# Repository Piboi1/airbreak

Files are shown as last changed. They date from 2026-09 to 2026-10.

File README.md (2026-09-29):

# MIT Rocket Team air brake – STL / STEP generator

`airbrake_stl.py` rebuilds the MIT Rocket Team (Prometheus) sliding-plate air brake.
It's pure Python 3 and needs no packages.

```
python3 airbrake_stl.py                 # extended (default)
python3 airbrake_stl.py --deploy 0      # retracted (any value 0..1)
python3 airbrake_stl.py --tube          # add the slotted 6 in airframe tube
python3 airbrake_stl.py --units in      # inches instead of mm
```

| Output | What it is |
|---|---|
| `airbrake_assembly.stl` | Whole assembly as one mesh (extended) |
| `airbrake_retracted.stl` | Same, with the leaves retracted |
| `airbrake_assembly.step` | **Open this one in CAD.** Exact geometry (true arcs, circles and cylinders, not facets); every part is one connected solid; 44 part instances, ready for Onshape mates and motion |
| `print/<part>_xN.stl` | One print-ready file per unique part, lying flat on the bed. `xN` is how many to print |
| `preview/motion.gif` | Rendered deployment cycle |

All files are in **millimetres**.

## Printing

| File | Qty | Notes |
|---|---|---|
| `frame_bottom_x1` | 1 | spoked frame that mounts in the tube |
| `tray_frame_x4` | 4 | ring segment either side of each tray |
| `tray_x2` | 2 | leaf guide tray (SLA resin in the real build) |
| `frame_middle_x1` | 1 | thin ring between the two trays |
| `leaf_x4` | 4 | 6061-T6 1/8 in plate in the real build |
| `hex_connector_x2` | 2 | double crank with a 1/4 in hex bore |
| `leaf_connector_x4` | 4 | links |
| `spacer_x4` | 4 | guide spacers under the servo bulkhead |
| `servo_bulkhead_x1` | 1 | |
| `servo_bracket_x2` | 2 | servo standoffs |
| `shaft_coupler_x1` | 1 | hex shaft to servo horn |
| `hex_shaft_x1` | 1 | or cut from 1/4 in steel hex stock |

Hardware you'll need to buy:
* 8 × #10 shoulder bolts (4 leaf pins, 4 crank pins)
* 8 × #10 washers
* 1 × large servo, about 1500 oz-in

Printed holes have 0.005 in (0.13 mm) radial clearance; change `HOLE_CLEAR` if your printer needs more.

## Onshape FeatureScript (`airbrake.fs`)

`airbrake.fs` builds the same air brake natively in Onshape, as real Onshape parts in meters.

1. In an Onshape document, create a **Feature Studio**. Replace its contents with `airbrake.fs` and commit.
2. Open a **Part Studio**. Add **MyCustomPart** from the custom features menu on the toolbar.
3. Adjust the options:
   * **Deployment (0–1):** 0 is stowed, 1 is fully out. Changing it rebuilds the model with the cranks, links and leaves moved to that position.
   * **Include servo / pins and washers / airframe tube:** toggles for those parts.
   * **Add mate connectors:** puts mate connectors on the shaft axis, every pin hole, and each leaf's slide direction.
4. For mates, insert the Part Studio into an Assembly and snap the mate connectors together:
   * **Revolute:** shaft to bottom frame; each leaf connector to its hex connector pin and its leaf pin.
   * **Fastened:** hex connectors to the shaft.
   * **Slider:** each leaf's slide connector to its tray's.

If Onshape reports a version error, replace the first two lines with the header from a newly created Feature Studio.

## Making it move in Onshape (STEP import)

Import `airbrake_assembly.step`. Onshape creates an Assembly tab with every part in its extended position. Then add these mates:

1. Group the frames, trays, tray frames, spacers, bulkhead, brackets and servo together, and fix the group.
2. Add a **Revolute** mate between the hex shaft and the bottom frame's bore. Fasten both hex connectors and the shaft coupler to the shaft.
3. Add a **Slider** mate from each leaf to its tray, along the channel.
4. Add a **Revolute** mate from each leaf connector to its crank pin hole on the hex connector.
5. Add a **Revolute** mate from each leaf connector to its pin hole on the leaf.

Dragging the hex shaft then drives all four leaves. The crank sweeps 90°, and each leaf travels exactly 2.25 in. At full extension the crank and link line up (dead centre), so drag on the leaves can't back-drive the servo.

## Accuracy

Values published on the MIT wiki:
* 4 sliding 6061-T6 leaves, each 3.5 in wide with 2.25 in extended (7.875 in² each, 31.5 in² total)
* two SLA trays stacked 90° apart, each spanning the full diameter and holding one opposing pair of leaves
* a hex connector and leaf connectors, driven by a servo on a bulkhead, with washers at the joints
* frames, spacers and a servo bulkhead
* 6 in series airframe (5.823 in ID / 6.00 in OD)

The team never published the other dimensions: plate thicknesses, frame sizes, stack
heights, linkage lengths and the servo's size. Those are estimates taken from the CAD
screenshots. The stack follows the PDR image, with 0.63 in between the two leaf levels.
All estimates are in the `PARAMETERS` block at the top of the script. The linkage is
re-solved automatically when you change them, and the script warns if a link would
hit the shaft.

Not modelled: radial screw holes into the airframe, fasteners, and the servo horn.

STL files are always triangle meshes, so they show triangle lines in any CAD tool. Use
them for printing, and use the STEP file for viewing and editing in CAD.

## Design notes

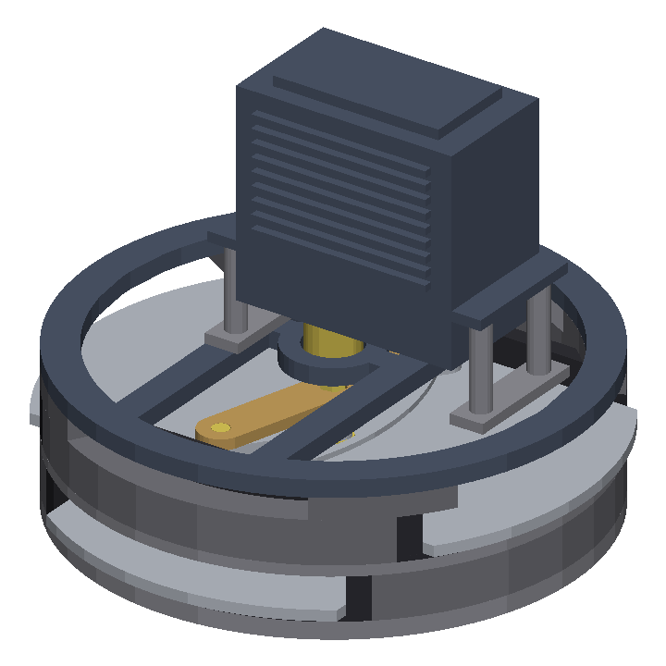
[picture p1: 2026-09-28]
preview/retracted.png

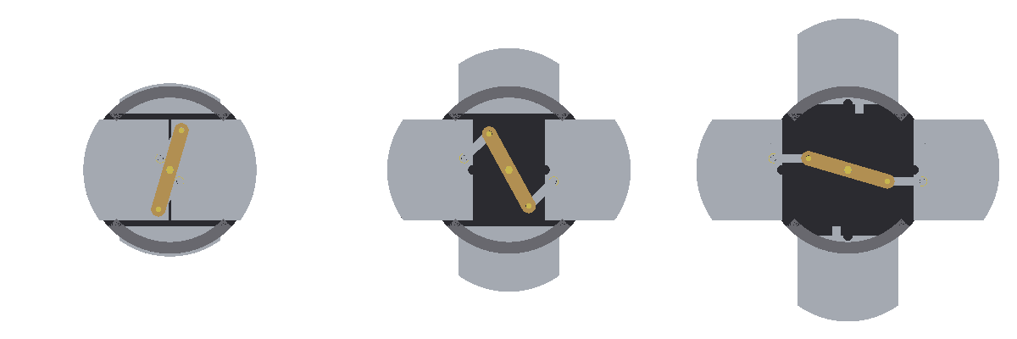
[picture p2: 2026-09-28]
preview/linkage_top.png

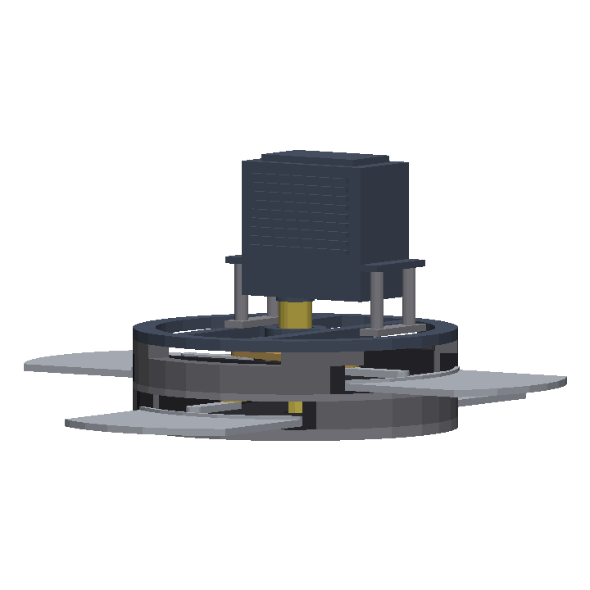
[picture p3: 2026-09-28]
preview/side.png

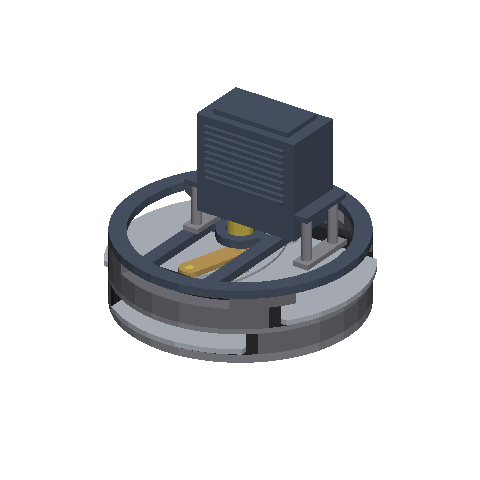
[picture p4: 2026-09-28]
preview/motion.gif

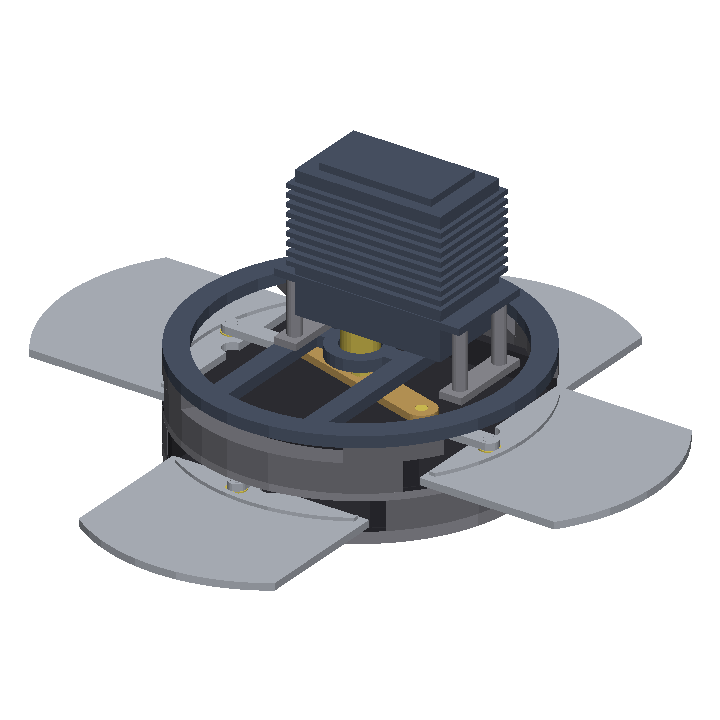
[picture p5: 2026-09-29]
preview/extended.png

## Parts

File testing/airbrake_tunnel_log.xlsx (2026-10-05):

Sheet: Settings
Air brake wind tunnel test log
Log every tunnel run on the Tunnel runs tab. Combined and Summary update by themselves.
How to use this workbook
1. Add each air brake version on the Designs tab (one row per version).
2. Log every tunnel measurement on Tunnel runs: one row per section (Nose, Air brake or Fin can) per run.
3. On Combined, add a row for each design, speed setpoint and deployment you tested. It averages repeat runs and adds the three sections together.
4. Summary shows drag coefficient against deployment and an estimated apogee for each design.
Blue text: values you type. Yellow fill: needs your number. Black text: formulas, leave them alone.
Need more rows? Select the last filled row on Tunnel runs or Combined and drag it down; the formulas copy with it.
Constants and inputs
Setting | Value | Unit | Source / note
Gas constant for dry air | 287.05 | J/(kg·K) | Standard value for dry air
Sutherland viscosity constant C1 | 1.458e-06 | kg/(m·s·K^0.5) | Sutherland's law for air (standard constants)
Sutherland temperature S | 110.4 | K | Sutherland's law for air (standard constants)
Gravity | 9.81 | m/s² | Standard gravity
Feet per metre | 3.28084 | ft/m | Unit conversion
Air density at launch site | 1.225 | kg/m³ | ISA sea level. Replace with your launch site value.
Target apogee | 800 | ft | Source: user-provided (ARC target)
Tunnel test-section area |  | m² | Fill in: width × height of your tunnel's test section
Blockage limit | 10% | fraction | Rule of thumb: above about 10% the walls inflate the drag reading

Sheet: Designs
Air brake designs
One row per version. Design ID is what the other tabs look up, so keep it short and unique.
Design ID | Description | Body tube OD (mm) | Reference area (m²) | Number of leaves | Leaf width (mm) | Leaf extension (mm) | Brake area, fully open (cm²) | Servo | Rocket mass (g) | CAD file / link | Notes
MIT-6in | Example: MIT Rocket Team CDR design (replace with your own) | 152.4 |  | 4 | 88.9 | 57.15 |  | 1500 oz-in industrial servo |  | airbrake.fs | Leaf size from the MIT wiki

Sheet: Tunnel runs
Wind tunnel runs
One row per section per run. Grey columns are calculated.
Run ID | Date | Design ID | Section | Deployment (%) | Speed setpoint (m/s) | Measured airspeed (m/s) | Measured force (N) | Tare force (N) | Air temp (°C) | Air pressure (kPa) | Model frontal area (cm²) | Notes | Air density (kg/m³) | Dynamic pressure (Pa) | Net drag (N) | Body OD (m) | Reference area (m²) | Section drag coefficient | Air viscosity (Pa·s) | Reynolds number | Blockage | Blockage check | Condition key
EX-1 | 2026-10-04 | MIT-6in | Air brake | 100 | 20 | 20.1 | 6.4 | 0.3 | 21 | 101.3 | 182.4 | Example row showing the format. Delete it.

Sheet: Combined
Whole-rocket drag from the three sections
Add one row per design, speed setpoint and deployment. Repeat runs are averaged; the three sections are added together.
 |  |  | Average net drag by section (N)
Design ID | Speed setpoint (m/s) | Deployment (%) | Nose | Air brake | Fin can | All three sections tested? | Total drag (N) | Average dynamic pressure (Pa) | Reference area (m²) | Whole-rocket drag coefficient | Air brake section drag, stowed (N) | Drag added by brakes (N) | Drag coefficient added by brakes
MIT-6in | 20 | 100

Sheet: Summary
Summary by design
Drag coefficients are averaged over every speed with all three sections tested.
Whole-rocket drag coefficient by brake deployment
Design ID | 0% open | 25% open | 50% open | 75% open | 100% open | Brake drag coefficient added at 100% | Tunnel runs logged
Estimated apogee
Vertical coast with constant drag, from burnout to apogee. Take burnout altitude and velocity from OpenRocket. Tunnel speeds are lower than flight speeds, so treat this as a comparison between designs.
Design ID | Coast mass (kg) | Burnout altitude (m) | Burnout velocity (m/s) | Drag coefficient, stowed | Drag coefficient, fully open | Reference area (m²) | Apogee, brakes stowed (ft) | Apogee, brakes open all coast (ft) | Target apogee (ft) | Can the brakes reach the target?

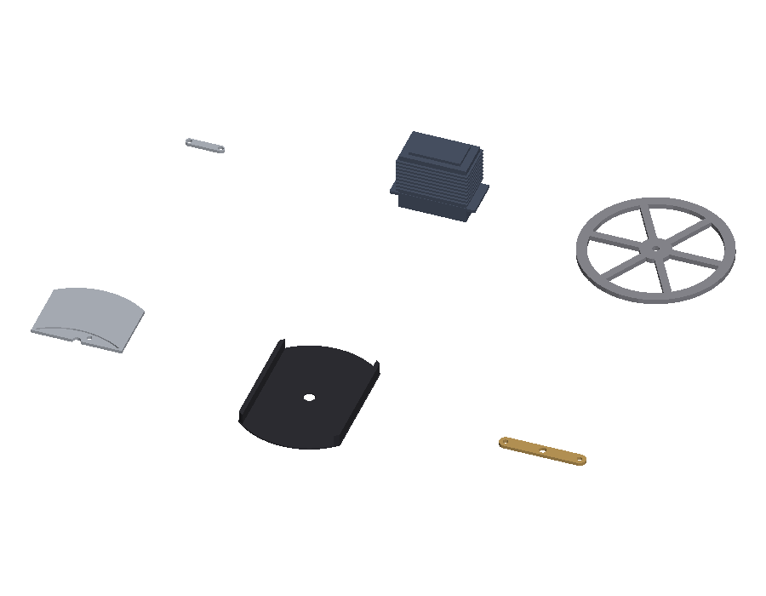
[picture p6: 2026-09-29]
preview/parts.png

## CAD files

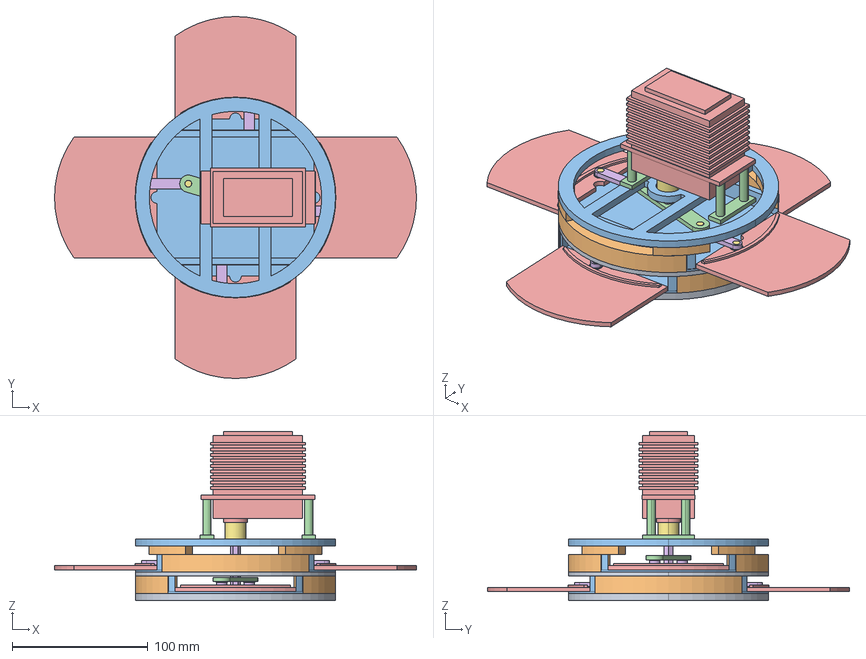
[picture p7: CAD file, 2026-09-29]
airbrake_assembly.step
266.7 x 266.7 x 124.6 mm
frame_bottom
tray_frame x 4
tray x 2
hex_connector x 2
leaf x 4
leaf_connector x 4
pin_leaf x 4
pin_crank x 4
washer x 8
frame_middle
spacer x 4
servo_bulkhead
servo_bracket x 2
servo
hex_shaft
shaft_coupler

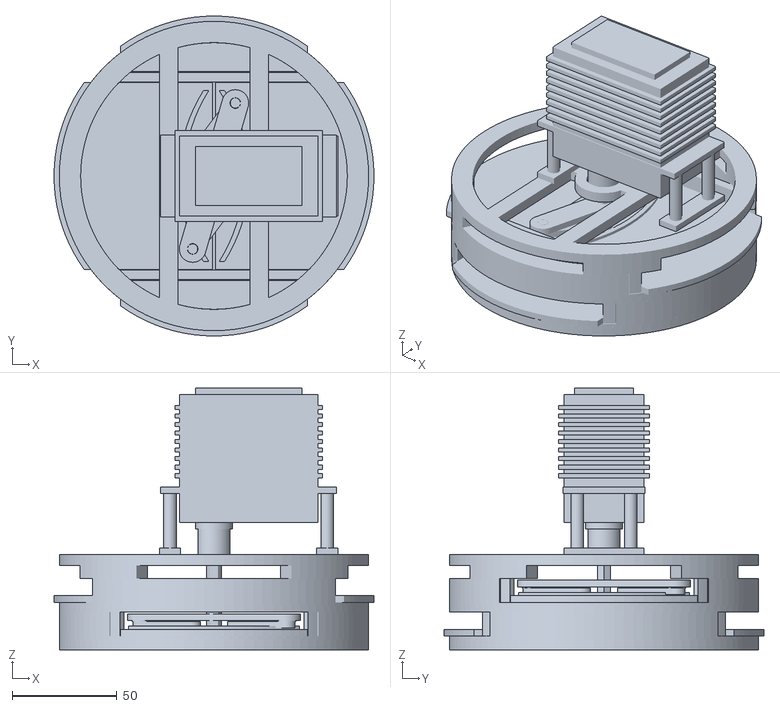
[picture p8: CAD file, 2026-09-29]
airbrake_retracted.stl
152.4 x 152.4 x 124.6

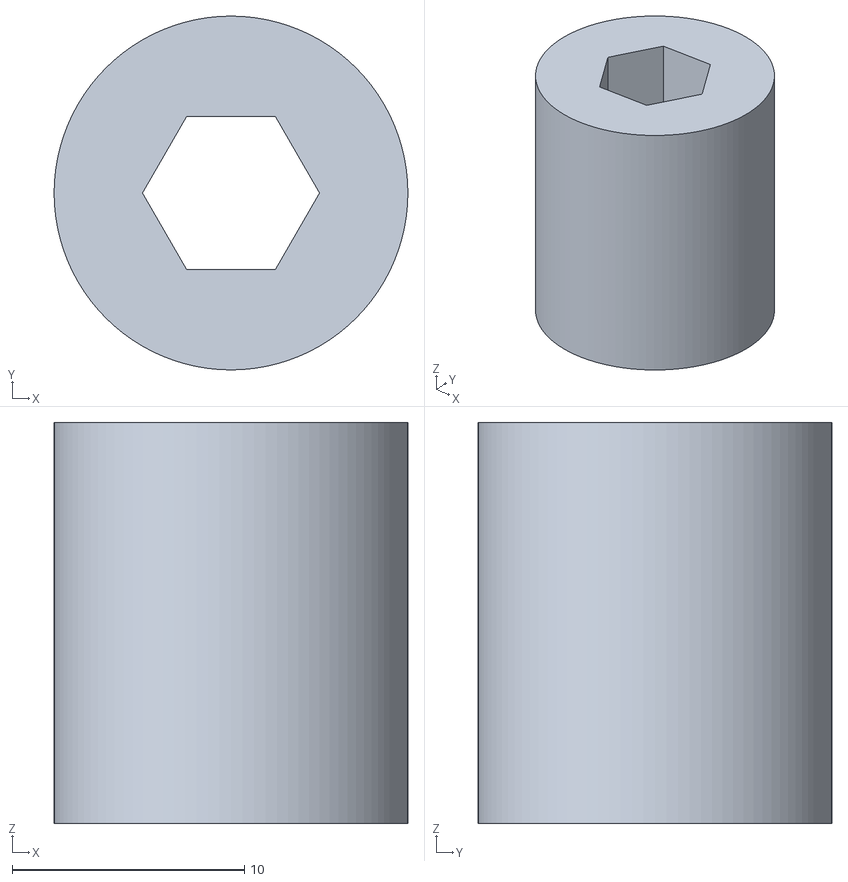
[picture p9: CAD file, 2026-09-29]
print/shaft_coupler_x1.stl
15.2 x 15.2 x 17.3

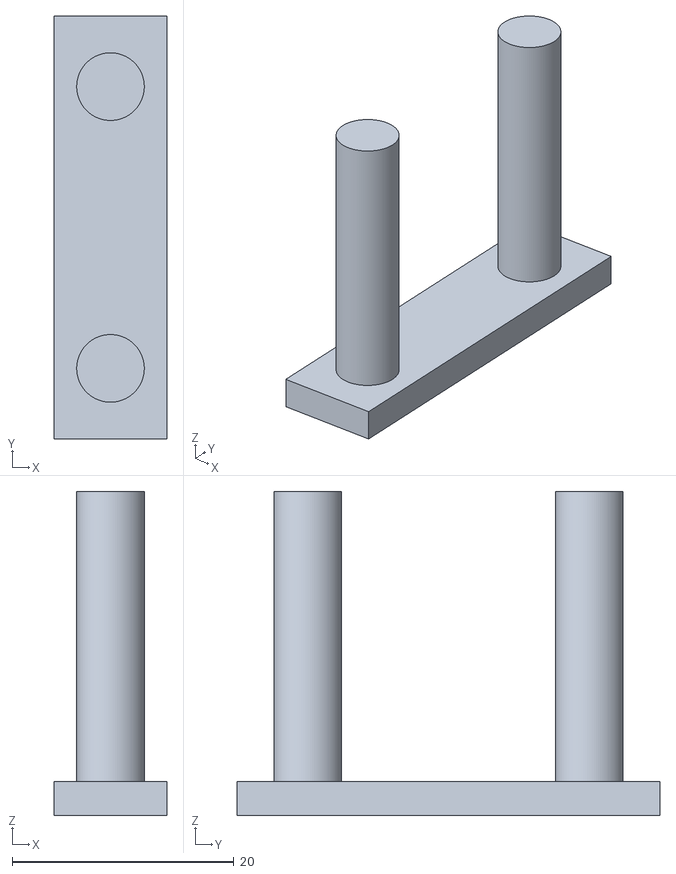
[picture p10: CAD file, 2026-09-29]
print/servo_bracket_x2.stl
10.2 x 38.1 x 29.2

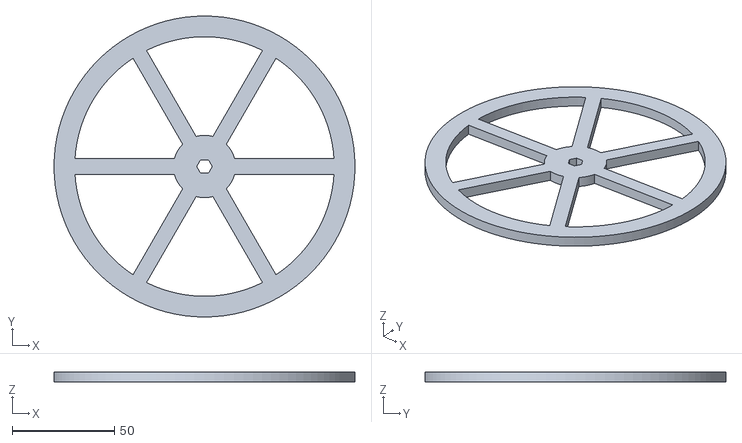
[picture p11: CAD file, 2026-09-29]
print/frame_bottom_x1.stl
147.3 x 147.3 x 5.08

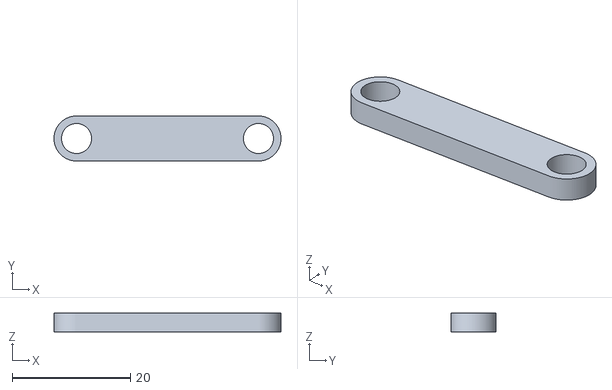
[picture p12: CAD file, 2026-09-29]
print/leaf_connector_x4.stl
38.4 x 7.62 x 3.17

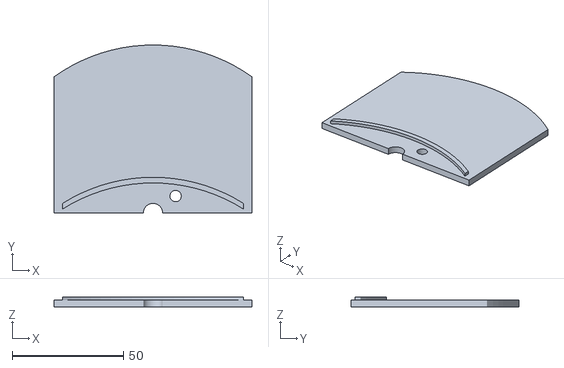
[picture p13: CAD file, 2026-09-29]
print/leaf_x4.stl
88.9 x 75.4 x 4.70

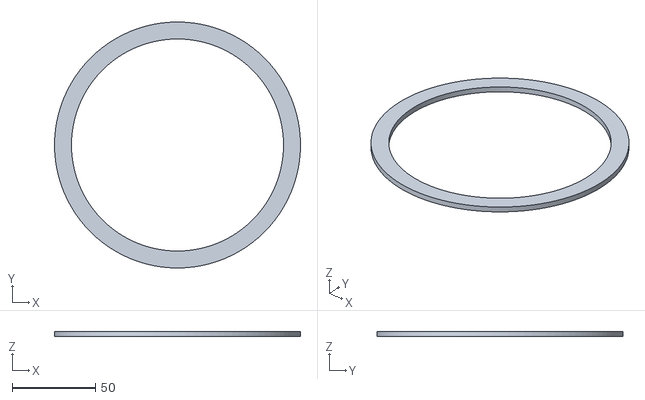
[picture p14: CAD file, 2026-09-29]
print/frame_middle_x1.stl
147.3 x 147.3 x 3.17

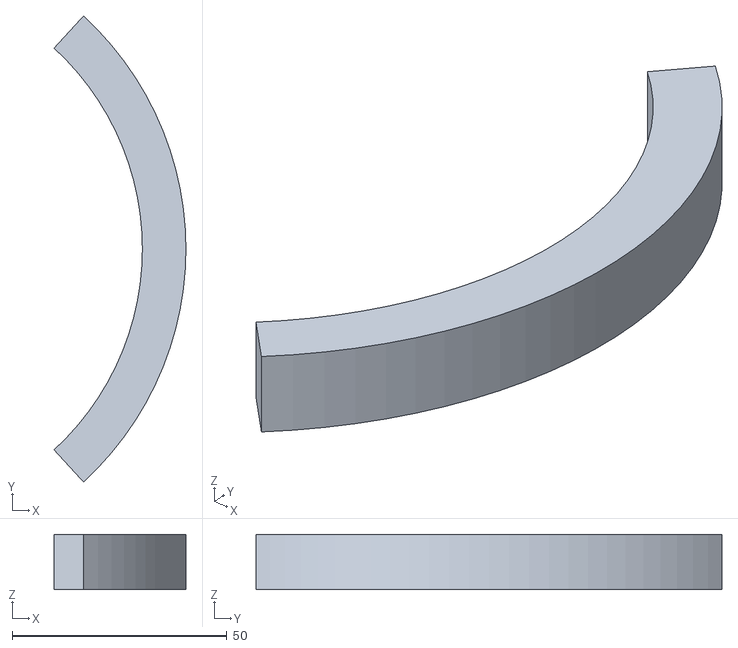
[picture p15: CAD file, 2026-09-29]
print/tray_frame_x4.stl
30.7 x 108.6 x 12.8

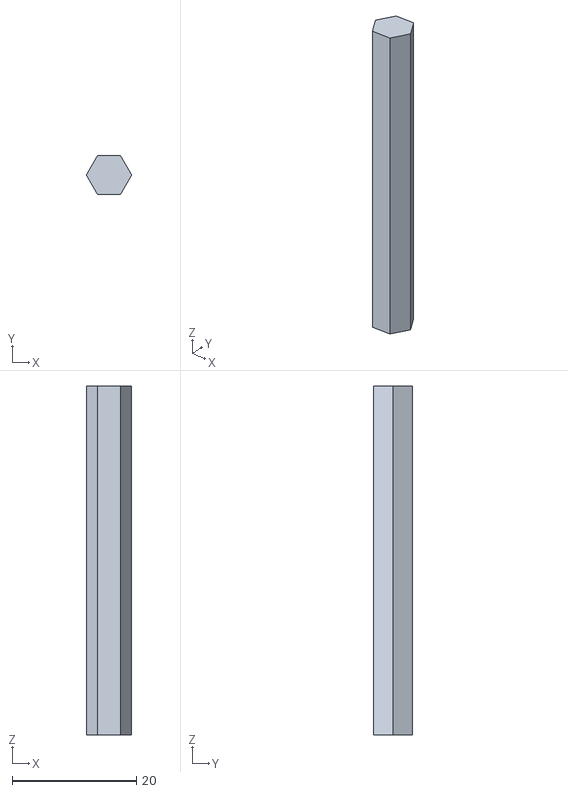
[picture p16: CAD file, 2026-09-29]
print/hex_shaft_x1.stl
7.33 x 6.35 x 56.3

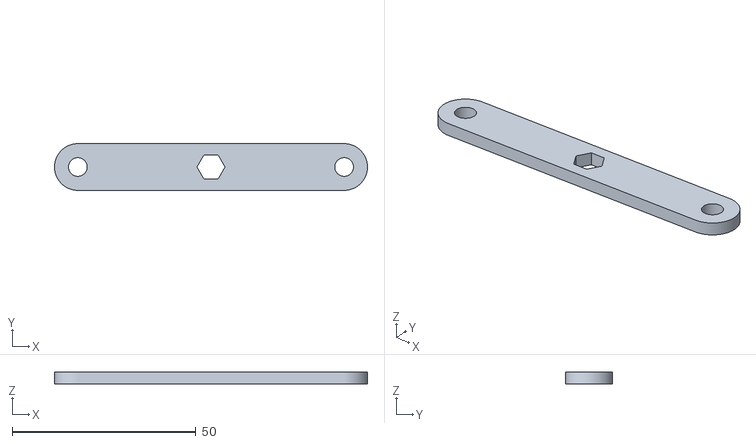
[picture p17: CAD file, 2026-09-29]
print/hex_connector_x2.stl
85.1 x 12.7 x 3.17

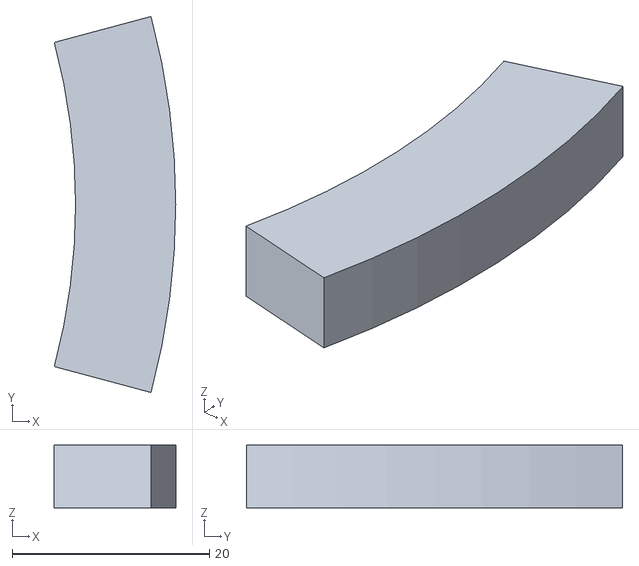
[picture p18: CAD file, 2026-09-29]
print/spacer_x4.stl
12.3 x 38.1 x 6.35

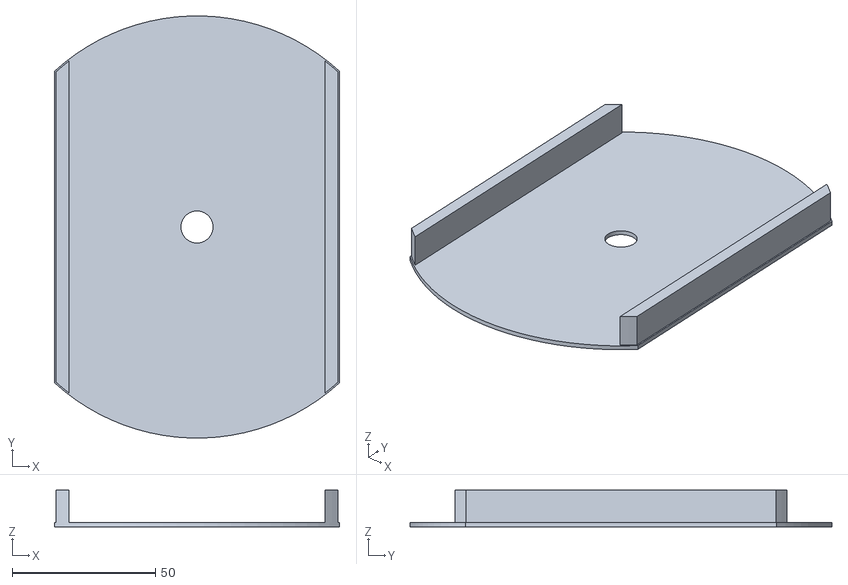
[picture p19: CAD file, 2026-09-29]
print/tray_x2.stl
99.6 x 147.2 x 12.8

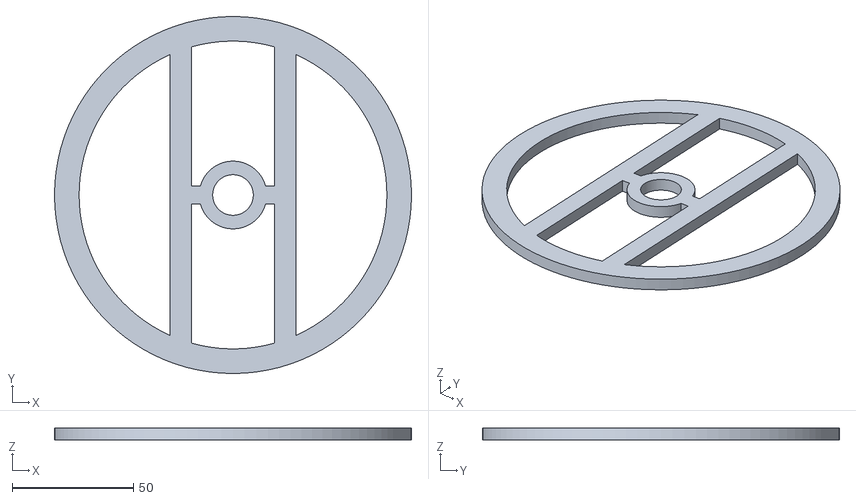
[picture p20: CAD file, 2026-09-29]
print/servo_bulkhead_x1.stl
147.3 x 147.3 x 5.08

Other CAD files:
airbrake_assembly.stl

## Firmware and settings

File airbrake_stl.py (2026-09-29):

#!/usr/bin/env python3
"""
MIT Rocket Team (Prometheus) air brake -- CDR configuration -- STL + STEP generator.

Reconstructed from the MIT Rocket Team wiki page "Air Brakes"
(wikis.mit.edu/confluence/display/RocketTeam/Air+Brakes) and its CAD screenshots.

What is taken directly from the wiki:
  * Sliding-plate design, 4 aluminium 6061-T6 leaves, one system on the sustainer
  * Leaf: 3.5 in wide x 2.25 in extended length  -> 7.875 (~7.88) in^2 per leaf,
    31.5 in^2 total
  * Leaves slide in SLA-printed trays, one tray per opposing pair of leaves, each
    tray spanning the full diameter; the two trays are stacked 90 deg apart
  * Leaves driven by a "hex connector" (double crank on a hex shaft) and a
    "leaf connector" (link) per leaf, with washers at every joint
  * CDR stack: frames that hold the trays and screw into the mission-package tube,
    spacers acting as guide rails, a servo bulkhead and a large industrial servo
  * Airframe from the MIT RT tube standard, 6 in series: 5.823 in ID x 6.00 in OD

Everything else (plate thicknesses, frame widths, stack heights, crank/link
lengths, servo size) was NOT published and is estimated from the screenshots.
All of those values are collected in the PARAMETERS block below.

Outputs:
    airbrake_assembly.step   exact B-rep assembly: one clean solid per part, true
                             arcs and cylinders, one occurrence per part instance
                             (open this one in Onshape / SolidWorks / Fusion)
    airbrake_assembly.stl    whole assembly as one triangle mesh
    print/<part>_xN.stl      one print-ready mesh per unique part, lying flat on
                             z = 0; N = how many the assembly needs

Usage:
    python3 airbrake_stl.py                   # extended
    python3 airbrake_stl.py --deploy 0        # fully retracted (0..1)
    python3 airbrake_stl.py --tube            # also add the slotted airframe tube
    python3 airbrake_stl.py --units in        # inches instead of mm

Pure Python 3 standard library; no dependencies.
"""

import argparse
import math
import os
import struct
import time

# ---------------------------------------------------------------------------
# PARAMETERS (inches). "wiki" = published value, everything else = estimate.
# ---------------------------------------------------------------------------
TUBE_ID = 5.823            # wiki (MIT RT tube standard, 6 in series)
TUBE_OD = 6.000            # wiki
FRAME_OD = 5.800           # slip fit inside the tube
FRAME_RING_W = 0.40        # radial width of the frame rings

LEAF_W = 3.50              # wiki
LEAF_EXT = 2.25            # wiki: extension beyond the airframe skin
LEAF_T = 0.125             # 1/8 in 6061-T6 plate
LEAF_R = TUBE_OD / 2.0     # outer edge arc = skin radius, so the leaf is flush when retracted
LEAF_GAP = 0.03            # straight inner edge sits this far from the axis when retracted
LEAF_NOTCH_R = 0.17        # semicircular notch in the inner edge that clears the hex shaft
LEAF_PIN = (0.40, 0.33)    # leaf-connector pin hole (x, y) in the leaf, beside the notch
LEAF_LIP_W = 0.10          # raised stop arc: hits the inside of the airframe at full extension
LEAF_LIP_H = 0.06
LEAF_LIP_INSET = 0.15      # lip stops short of the leaf's side edges

TRAY_FLOOR_T = 0.06        # SLA tray floor
TRAY_RAIL_W = 0.20         # guide rail on each side of the leaf channel
TRAY_CLEAR = 0.01          # side clearance between leaf and rail
TRAY_HOLE_R = 0.22         # shaft clearance in the tray floor
TRAY_LEDGE = 0.02          # floor ledge left around the outside of the rails

CONN_T = 0.125             # hex connector / leaf connector thickness
CONN_W = 0.30              # leaf connector (link) width
CRANK_W = 0.50             # hex connector width
WASHER_T = 0.02
WASHER_R = 0.17            # #10 washer
PIN_D = 0.19               # #10 shoulder bolt
HOLE_CLEAR = 0.005         # radial clearance on printed holes
HEX_AF = 0.25              # 1/4 in hex shaft (across flats)

CRANK_SWEEP_DEG = 90.0     # servo travel from retracted to extended; at full extension the
                           # crank pin, link and leaf pin line up (dead centre), so drag on
                           # the leaves cannot back-drive the servo

FRAME_T = 0.20             # bottom frame / servo bulkhead thickness
MID_FRAME_T = 0.125        # thin frame between the two trays
SPACER_H = 0.25            # guide spacers between the top tray and the servo bulkhead
SPACER_SPAN_DEG = 30.0

SERVO_BODY = (2.60, 1.50, 2.40)   # length, width, height of the industrial servo
SERVO_OUTPUT_OFFSET = 0.65        # output spline offset from the body centre
SERVO_EAR_LEN = 0.35              # mounting ear overhang at each end
SERVO_EAR_T = 0.12
SERVO_EAR_Z = 0.55                # ear height above the output face
SERVO_FINS = 9
BRACKET_H = 0.60                  # bulkhead top to servo output face
COUPLER_R = 0.30

SEG = 96                   # mesh facets per full circle (STL only; the STEP uses true arcs)

# Derived
TRAY_H = TRAY_FLOOR_T + LEAF_T + WASHER_T + CONN_T + WASHER_T + CONN_T + 0.03
CHANNEL_HW = LEAF_W / 2 + TRAY_CLEAR
TRAY_HW = CHANNEL_HW + TRAY_RAIL_W


# ---------------------------------------------------------------------------
# 2D profiles: closed loops of exact segments
#   ('L', p0, p1)              straight line
#   ('A', centre, r, a0, a1)   circular arc from angle a0 to a1 (CCW if a1 > a0)
# ---------------------------------------------------------------------------
def Ln(p, q):
    return ("L", (float(p[0]), float(p[1])), (float(q[0]), float(q[1])))


def Ar(c, r, a0, a1):
    return ("A", (float(c[0]), float(c[1])), float(r), float(a0), float(a1))


def seg_start(s):
    if s[0] == "L":
        return s[1]
    _, c, r, a0, _ = s
    return (c[0] + r * math.cos(a0), c[1] + r * math.sin(a0))


def seg_end(s):
    if s[0] == "L":
        return s[2]
    _, c, r, _, a1 = s
    return (c[0] + r * math.cos(a1), c[1] + r * math.sin(a1))


def seg_rev(s):
    return ("L", s[2], s[1]) if s[0] == "L" else ("A", s[1], s[2], s[4], s[3])


def seg_points(s):
    """Tessellation of a segment: start point included, end point excluded."""
    if s[0] == "L":
        return [s[1]]
    _, c, r, a0, a1 = s
    n = max(2, int(math.ceil(abs(a1 - a0) / (2 * math.pi) * SEG)))
    return [(c[0] + r * math.cos(a0 + (a1 - a0) * t / n),
             c[1] + r * math.sin(a0 + (a1 - a0) * t / n)) for t in range(n)]


def loop_poly(loop):
    return [p for s in loop for p in seg_points(s)]


def loop_rev(loop):
    return [seg_rev(s) for s in reversed(loop)]


def loop_xform(loop, ang=0.0, dx=0.0, dy=0.0):
    def tp(p):
        x, y = rot2(p[0], p[1], ang)
        return (x + dx, y + dy)
    out = []
    for s in loop:
        if s[0] == "L":
            out.append(Ln(tp(s[1]), tp(s[2])))
        else:
            out.append(Ar(tp(s[1]), s[2], s[3] + ang, s[4] + ang))
    return out


def poly_loop(pts):
    return [Ln(pts[i], pts[(i + 1) % len(pts)]) for i in range(len(pts))]


def circle_loop(r, cx=0.0, cy=0.0):
    return [Ar((cx, cy), r, 0.0, math.pi), Ar((cx, cy), r, math.pi, 2 * math.pi)]


def rect_loop(x0, y0, x1, y1):
    return poly_loop([(x0, y0), (x1, y0), (x1, y1), (x0, y1)])


def hex_loop(af, cx=0.0, cy=0.0):
    r = af / math.sqrt(3)
    return poly_loop([(cx + r * math.cos(k * math.pi / 3), cy + r * math.sin(k * math.pi / 3))
                      for k in range(6)])


def stadium_loop(p, q, w):
    ang = math.atan2(q[1] - p[1], q[0] - p[0])
    r = w / 2
    n = (-math.sin(ang) * r, math.cos(ang) * r)
    return [Ar(p, r, ang + math.pi / 2, ang + 3 * math.pi / 2),
            Ln((p[0] - n[0], p[1] - n[1]), (q[0] - n[0], q[1] - n[1])),
            Ar(q, r, ang - math.pi / 2, ang + math.pi / 2),
            Ln((q[0] + n[0], q[1] + n[1]), (p[0] + n[0], p[1] + n[1]))]


def sector_loop(r_in, r_out, a0, a1):
    return [Ar((0, 0), r_out, a0, a1),
            Ln((r_out * math.cos(a1), r_out * math.sin(a1)), (r_in * math.cos(a1), r_in * math.sin(a1))),
            Ar((0, 0), r_in, a1, a0),
            Ln((r_in * math.cos(a0), r_in * math.sin(a0)), (r_out * math.cos(a0), r_out * math.sin(a0)))]


def cy_(x, r):
    """y on a circle of radius r at abscissa x."""
    return math.sqrt(max(r * r - x * x, 0.0))


def rot2(x, y, a):
    return x * math.cos(a) - y * math.sin(a), x * math.sin(a) + y * math.cos(a)


def _area2(poly):
    return sum(poly[i][0] * poly[(i + 1) % len(poly)][1] -
               poly[(i + 1) % len(poly)][0] * poly[i][1] for i in range(len(poly)))


def _cross(o, a, b):
    return (a[0] - o[0]) * (b[1] - o[1]) - (a[1] - o[1]) * (b[0] - o[0])


def _inside(p, poly):
    inside = False
    for i in range(len(poly)):
        a, b = poly[i], poly[i - 1]
        if (a[1] > p[1]) != (b[1] > p[1]):
            if p[0] < a[0] + (p[1] - a[1]) * (b[0] - a[0]) / (b[1] - a[1]):
                inside = not inside
    return inside


# ---------------------------------------------------------------------------
# Triangulation (STL only): ear clipping with holes bridged in
# ---------------------------------------------------------------------------
def _segments_cross(p1, p2, q1, q2):
    d1, d2 = _cross(q1, q2, p1), _cross(q1, q2, p2)
    d3, d4 = _cross(p1, p2, q1), _cross(p1, p2, q2)
    return ((d1 > 1e-12 and d2 < -1e-12) or (d1 < -1e-12 and d2 > 1e-12)) and \
           ((d3 > 1e-12 and d4 < -1e-12) or (d3 < -1e-12 and d4 > 1e-12))


def _on_segment(p, a, b):
    if p == a or p == b or abs(_cross(a, b, p)) > 1e-12:
        return False
    return min(a[0], b[0]) - 1e-12 <= p[0] <= max(a[0], b[0]) + 1e-12 and \
        min(a[1], b[1]) - 1e-12 <= p[1] <= max(a[1], b[1]) + 1e-12


def _bridge_holes(outer, holes):
    poly = list(outer)
    pending = sorted(holes, key=lambda h: -max(p[0] for p in h))
    for n, h in enumerate(pending):
        m = max(range(len(h)), key=lambda i: h[i][0])
        M = h[m]
        edges = [(poly[i], poly[(i + 1) % len(poly)]) for i in range(len(poly))]
        for hh in pending[n:]:
            edges += [(hh[i], hh[(i + 1) % len(hh)]) for i in range(len(hh))]
        verts = [a for a, _ in edges]
        order = sorted(range(len(poly)),
                       key=lambda i: (poly[i][0] - M[0]) ** 2 + (poly[i][1] - M[1]) ** 2)
        pick = None
        for i in order:
            P = poly[i]
            mid = ((M[0] + P[0]) / 2, (M[1] + P[1]) / 2)
            if not _inside(mid, outer) or any(_inside(mid, hh) for hh in holes):
                continue
            if any(_on_segment(v, M, P) for v in verts):
                continue
            if not any(_segments_cross(M, P, a, b) for a, b in edges):
                pick = i
                break
        if pick is None:
            raise ValueError("could not bridge a hole")
        poly = poly[:pick + 1] + h[m:] + h[:m + 1] + poly[pick:]
    return poly


def triangulate(outer, holes=()):
    """outer CCW, holes CW. Returns 2D triangles (CCW)."""
    poly = _bridge_holes(outer, holes) if holes else list(outer)
    n = len(poly)
    nxt = [(i + 1) % n for i in range(n)]
    prv = [(i - 1) % n for i in range(n)]

    def convex(i):
        return _cross(poly[prv[i]], poly[i], poly[nxt[i]]) > 1e-12

    reflex = {i for i in range(n) if not convex(i)}

    def ear(i):
        if not convex(i):
            return False
        a, b, c = poly[prv[i]], poly[i], poly[nxt[i]]
        for j in reflex:
            p = poly[j]
            if p == a or p == b or p == c:
                continue
            if _cross(a, b, p) >= 0 and _cross(b, c, p) >= 0 and _cross(c, a, p) >= 0:
                return False
        return True

    tris = []
    count, i, stall = n, 0, 0
    while count > 3:
        if ear(i):
            a, c = prv[i], nxt[i]
            tris.append((poly[a], poly[i], poly[c]))
            nxt[a], prv[c] = c, a
            reflex.discard(i)
            for j in (a, c):
                if j in reflex and convex(j):
                    reflex.discard(j)
            count -= 1
            i, stall = c, 0
        else:
            i = nxt[i]
            stall += 1
            if stall > 2 * count:
                raise ValueError("triangulation failed")
    tris.append((poly[prv[i]], poly[i], poly[nxt[i]]))
    return [t for t in tris if abs(_cross(*t)) > 1e-14]


# ---------------------------------------------------------------------------
# Solids. A Body is a z-extrusion of a profile (outline + holes). Bodies can be
# stacked: a child on the top (or bottom) face either sits strictly inside the
# parent's face (a boss) or strictly contains it (a flange), so every part is a
# single connected solid with exact planar and cylindrical faces.
# ---------------------------------------------------------------------------
class Body:
    def __init__(self, outline, z0, z1, holes=(), top=(), bottom=()):
        self.outline = outline if _area2(loop_poly(outline)) > 0 else loop_rev(outline)
        self.holes = [h if _area2(loop_poly(h)) < 0 else loop_rev(h) for h in holes]
        self.z0, self.z1 = float(z0), float(z1)
        self.parent, self.side, self.outer = None, None, False
        self.top, self.bottom = list(top), list(bottom)
        for side, kids in (("top", self.top), ("bottom", self.bottom)):
            for k in kids:
                k.parent, k.side = self, side
                k.outer = _inside(loop_poly(self.outline)[0], loop_poly(k.outline))
                assert abs((k.z0 if side == "top" else k.z1) - (self.z1 if side == "top" else self.z0)) < 1e-9
            if any(k.outer for k in kids):
                assert len(kids) == 1, "a flange must be the only child on that face"
        for loop in [self.outline] + self.holes:
            for i, s in enumerate(loop):
                e, b = seg_end(s), seg_start(loop[(i + 1) % len(loop)])
                assert math.hypot(e[0] - b[0], e[1] - b[1]) < 1e-7, "open profile"

    def nodes(self):
        out = [self]
        for k in self.top + self.bottom:
            out += k.nodes()
        return out

    def cap(self, which):
        """Loops (by owner) of the planar face on this body's top/bottom, or None.
        Returns list of (owner_body, loop_index, level) where level is 'z1' or 'z0'."""
        up = which == "top"
        parent_here = self.parent is not None and self.side == ("bottom" if up else "top")
        kids = self.top if up else self.bottom
        mine = "z1" if up else "z0"
        other = "z0" if up else "z1"
        if parent_here:
            if not self.outer:
                return None
            refs = [(self, i, mine) for i in range(1 + len(self.holes))]
            return refs + [(self.parent, 0, other)]
        if kids and kids[0].outer:
            return None
        refs = [(self, i, mine) for i in range(1 + len(self.holes))]
        return refs + [(k, 0, other) for k in kids]


def body_loops(b):
    return [b.outline] + b.holes


class Part:
    def __init__(self, name, bodies, printable=True, note=""):
        self.name, self.bodies, self.printable, self.note = name, bodies, printable, note
        self._mesh = None

    def mesh(self):
        if self._mesh is None:
            self._mesh = [t for b in self.bodies for t in body_mesh(b)]
        return self._mesh


def body_mesh(root):
    out = []
    for N in root.nodes():
        for loop in body_loops(N):
            pts = loop_poly(loop)
            for i in range(len(pts)):
                s, e = pts[i], pts[(i + 1) % len(pts)]
                a, b = (s[0], s[1], N.z0), (e[0], e[1], N.z0)
                c, d = (e[0], e[1], N.z1), (s[0], s[1], N.z1)
                out += [(a, b, c), (a, c, d)]
        for which in ("top", "bottom"):
            refs = N.cap(which)
            if refs is None:
                continue
            z = N.z1 if which == "top" else N.z0
            polys = [loop_poly(body_loops(o)[i]) for o, i, _ in refs]
            outer, inner = polys[0], polys[1:]
            # loops owned by another body are the far side of the step: flip them
            inner = [p if o is N else p[::-1] for p, (o, _, _) in zip(inner, refs[1:])]
            for t in triangulate(outer, inner):
                tri = tuple((p[0], p[1], z) for p in t)
                out.append(tri if which == "top" else tri[::-1])
    return out


class Instance:
    """A part placed by a rotation about Z followed by a translation."""
    def __init__(self, part, angle=0.0, x=0.0, y=0.0, z=0.0, label=None):
        self.part, self.angle, self.pos = part, angle, (x, y, z)
        self.label = label or part.name

    def apply(self, v):
        x, y = rot2(v[0], v[1], self.angle)
        return (x + self.pos[0], y + self.pos[1], v[2] + self.pos[2])


# ---------------------------------------------------------------------------
# Kinematics: offset slider-crank per leaf, solved so the leaf travels LEAF_EXT.
# Crank pin at rc*(cos phi, sin phi); the leaf pin runs along the line x = e.
# ---------------------------------------------------------------------------
def _slider(rc, l, phi, e):
    dx = rc * math.cos(phi) - e
    return rc * math.sin(phi) + math.sqrt(max(l * l - dx * dx, 0.0))


def solve_linkage():
    """Crank radius rc and link length l such that the leaf pin travels exactly
    LEAF_EXT over CRANK_SWEEP_DEG, ending at dead centre (crank pin on x = e)."""
    e, s_ret = LEAF_PIN
    s_ext = s_ret + LEAF_EXT
    sweep = math.radians(CRANK_SWEEP_DEG)

    def geometry(rc):
        phi_e = math.acos(e / rc)
        return phi_e, s_ext - rc * math.sin(phi_e)

    def err(rc):
        phi_e, l = geometry(rc)
        return _slider(rc, l, phi_e - sweep, e) - s_ret

    lo, hi = e + 1e-6, CHANNEL_HW - CRANK_W / 2
    if err(lo) * err(hi) > 0:
        raise ValueError("no crank radius fits in the tray channel; adjust the linkage parameters")
    for _ in range(200):
        mid = (lo + hi) / 2
        if err(lo) * err(mid) <= 0:
            hi = mid
        else:
            lo = mid
    rc = (lo + hi) / 2
    phi_e, l = geometry(rc)
    return rc, l, phi_e - sweep, phi_e


def shaft_clearance(rc, l, phi_r, phi_e):
    """Smallest gap between a leaf connector and the hex shaft over the stroke."""
    e = LEAF_PIN[0]
    worst = float("inf")
    for i in range(201):
        phi = phi_r + (phi_e - phi_r) * i / 200
        p = (rc * math.cos(phi), rc * math.sin(phi))
        q = (e, _slider(rc, l, phi, e))
        dx, dy = q[0] - p[0], q[1] - p[1]
        t = max(0.0, min(1.0, -(p[0] * dx + p[1] * dy) / (dx * dx + dy * dy)))
        d = math.hypot(p[0] + t * dx, p[1] + t * dy)
        worst = min(worst, d - CONN_W / 2 - HEX_AF / math.sqrt(3))
    return worst


# ---------------------------------------------------------------------------
# Part geometry (local frames, bottom face on z = 0)
# ---------------------------------------------------------------------------
def pin_hole(x, y):
    return circle_loop(PIN_D / 2 + HOLE_CLEAR, x, y)


def hex_hole():
    return hex_loop(HEX_AF + 2 * HOLE_CLEAR)


def make_leaf():
    """Outer edge: arc on the airframe OD (flush when stowed). Inner edge: straight,
    meeting the opposite leaf at the axis, with a notch around the shaft. A raised
    stop lip hits the inside of the airframe at full extension."""
    hw = LEAF_W / 2
    a = math.atan2(cy_(hw, LEAF_R), hw)
    rn = LEAF_NOTCH_R
    outline = [Ar((0, 0), LEAF_R, a, math.pi - a),
               Ln((-hw, cy_(hw, LEAF_R)), (-hw, LEAF_GAP)),
               Ln((-hw, LEAF_GAP), (-rn, LEAF_GAP)),
               Ar((0, LEAF_GAP), rn, math.pi, 0.0),
               Ln((rn, LEAF_GAP), (hw, LEAF_GAP)),
               Ln((hw, LEAF_GAP), (hw, cy_(hw, LEAF_R)))]
    d = LEAF_EXT + (TUBE_OD - TUBE_ID) / 2        # stop arc = skin arc moved inboard
    xl = hw - LEAF_LIP_INSET
    c1, c2 = (0.0, -d), (0.0, -d - LEAF_LIP_W)
    b1 = math.atan2(cy_(xl, LEAF_R), xl)
    lip = [Ar(c1, LEAF_R, b1, math.pi - b1),
           Ln((-xl, c1[1] + cy_(xl, LEAF_R)), (-xl, c2[1] + cy_(xl, LEAF_R))),
           Ar(c2, LEAF_R, math.pi - b1, b1),
           Ln((xl, c2[1] + cy_(xl, LEAF_R)), (xl, c1[1] + cy_(xl, LEAF_R)))]
    assert c2[1] + cy_(xl, LEAF_R) > LEAF_GAP + 0.02, "stop lip runs off the leaf"
    body = Body(outline, 0, LEAF_T, [pin_hole(*LEAF_PIN)],
                top=[Body(lip, LEAF_T, LEAF_T + LEAF_LIP_H)])
    return Part("leaf", [body], note="6061-T6 1/8 in plate in the real build")


def _clipped_rect(x0, x1, r):
    """Region x0 <= x <= x1 inside a circle of radius r (ends are true arcs)."""
    a0, a1 = math.atan2(cy_(x1, r), x1), math.atan2(cy_(x0, r), x0)
    return [Ln((x1, -cy_(x1, r)), (x1, cy_(x1, r))),
            Ar((0, 0), r, a0, a1),
            Ln((x0, cy_(x0, r)), (x0, -cy_(x0, r))),
            Ar((0, 0), r, -a1, -a0)]


def make_tray():
    r = FRAME_OD / 2
    rails = [Body(_clipped_rect(x0, x1, r - TRAY_LEDGE), TRAY_FLOOR_T, TRAY_H)
             for x0, x1 in ((-TRAY_HW + TRAY_LEDGE, -CHANNEL_HW), (CHANNEL_HW, TRAY_HW - TRAY_LEDGE))]
    floor = Body(_clipped_rect(-TRAY_HW, TRAY_HW, r), 0, TRAY_FLOOR_T,
                 [circle_loop(TRAY_HOLE_R)], top=rails)
    return Part("tray", [floor], note="SLA resin in the real build")


def make_tray_frame():
    a = math.acos(TRAY_HW / (FRAME_OD / 2))
    r0, r1 = FRAME_OD / 2 - FRAME_RING_W, FRAME_OD / 2
    return Part("tray_frame", [Body(sector_loop(r0, r1, -a, a), 0, TRAY_H)],
                note="ring segment either side of each tray")


def make_mid_frame():
    r1 = FRAME_OD / 2
    return Part("frame_middle", [Body(circle_loop(r1), 0, MID_FRAME_T,
                                      [circle_loop(r1 - FRAME_RING_W)])])
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

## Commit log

2026-09-28 Add parametric STL generator for MIT RT CDR air brake
    Pure-Python (stdlib only) generator for the sliding-plate air brake
    described on the MIT Rocket Team wiki, plus generated extended and
    retracted assemblies and preview renders.
    Claude-Session: https://claude.ai/code/session_01YH5FpMEdC1av5jyMPxn9dF
    [airbrake_assembly.stl, airbrake_retracted.stl]
2026-09-28 Pancake the stack, add print STLs and STEP assembly
    - Stack the two trays directly on a thin middle frame (0.63 in between leaf
    levels, as in the PDR image) instead of spacer + full frame
    - Real holes: pin holes, hex bores, frame windows (hole-aware triangulation)
    - Offset slider-crank solved to end at dead centre, so the stroke is
    monotonic and exactly 2.25 in
    - print/: one flat, print-ready STL per unique part with quantities
    - airbrake_assembly.step: AP214 assembly, one product per part, for mates
    - Previews including a deployment animation
    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
    [airbrake_assembly.step, airbrake_assembly.stl, airbrake_retracted.stl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]
2026-09-29 Exact B-rep STEP: true arcs/cylinders, one solid per part
    - Profiles are now exact line/arc segments; the STEP writer emits LINE/CIRCLE
    edges and PLANE/CYLINDRICAL_SURFACE faces instead of faceted polylines
    (file 2.9 MB -> 0.36 MB)
    - Parts are single connected solids: stacked bodies (bosses and flanges)
    share edges, so the leaf lip, tray rails and servo fins/ears merge
    - Tray frame split into single ring segments (x4)
    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
    [airbrake_assembly.step, airbrake_assembly.stl, airbrake_retracted.stl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]
2026-09-29 Add Onshape FeatureScript version of the air brake
    MyCustomPart feature: builds every part as a named Onshape part (meters),
    with a Deployment slider that drives the linkage, stacked bodies merged
    into single parts, and mate connectors at every joint for assembly.
    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
2026-10-05 Add wind tunnel test log workbook
    Five tabs (Settings, Designs, Tunnel runs, Combined, Summary) for logging
    split-section tunnel runs per air brake design. Formulas compute air
    density, dynamic pressure, net drag, section and whole-rocket drag
    coefficients, brake drag increment, blockage and estimated apogee.
    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
    [airbrake_tunnel_log.xlsx]
2026-10-27 Add screwed V1 and compact V2 BT80 airbrake CAD, guides and exports
    Built in Onshape from the supplied FeatureScript (kept unchanged as
    onshape/fs/v0_original.fs); onshape/tools/build_fs.py applies 39 asserted
    patches to produce onshape/fs/airbrake_v1_v2.fs.
    V1: every bonded joint that has room is now an M3 (M4 hinge) screw joint:
    seam ribs, hinge screws, open-top catch caps, sleeve pads, dock ring,
    cradle pads and lid ears, with hardware modelled as parts and reference
    BT80 tubes carrying the drill holes.
    V2: fins move into a 64.6 mm head inside the upper BT80 tube; the tube
    is slit and the cut-outs are glued to the fins. Thick supports between
    the fins and under the fins replace the uppe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
2026-10-27 Add V2 fin-height preview (0 / 14 / 22 mm latch-stack drop)
    Cut-away preview of the real V2 model, trimmed from the top and
    re-aligned, to compare how close the fin top sits to the head top.
    Not an engineered design: the latch stack is not yet re-engineered.
    Claude-Session: https://claude.ai/code/session_017cUi44sQmQqbAyaMYUK8NJ
2026-10-27 WIP: V2 compact head re-laid out for a 22 mm latch drop (FeatureScript source and tools only)
    Source and tooling for the shorter V2. Not yet rebuilt or verified in Onshape (API rate limit on the
    part-studio features endpoint); exports and guides in the repo still describe the previous V2.
    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
2026-10-28 V2 at 22 mm latch drop: rebuilt studios, assembly, exports, figures and guide
    Printed housing 118 -> 91.8 mm, whole printed assembly 178.5 -> 152.3 mm. Fin window raised to
    clear the fin top, top ring raised to z 58.8, catch-cap socket opened through a 0.1 mm skin.
    No printed-part overlaps closed or open; latch holds at 14 deg and releases at 16 deg, cams
    touch between 22 and 26 deg (CAD interference scan; not tested on a print).
    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
2026-10-30 Add V3 (SG90 straight on the rotor), torque check, and fix V2 reference tube window
    V3: spring cartridge, trigger and all layers under the rotor replaced by one SG90 hung from two housing
    posts; printed set 169 -> 108 g, overall 152.3 -> 105.5 mm. Studios, ASM-V3, STEP/STL, figures, guide.
    V2: reference upper-tube window raised 60.2 -> 63.8 mm (fin tip would have hit the tube); V2 studios,
    assembly, STEP and figures rebuilt. Offline sweep/timing scripts added.
    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
2026-10-30 Add V3 mechanics diagram document and the measurement/figure scripts behind it
    Staged cut-aways, side schematic, latch and cam plan sections, measured timing curve (latch frees at
    14 deg, cam first moves the fin at 26 deg, 14 deg kick), load path and a per-part motion table.
    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
2026-10-30 Add design history document: every iteration and why each switch happened
    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
2026-10-30 V3 flush: servo moved up inside the housing, flush with the housing bottom
    Lower bearing, thrust collar and spokes raised above the horn (bearing z -0.8..2.2), rotor bottom at
    z -8.7, servo posts hang from the raised spokes, 0.7 mm base-ring relief for the tab. Overall length
    105.5 -> 91.8 mm, printed set 108 -> 106 g. Studios, ASM-V3, STEP/STL, figures, guides and history updated.
    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
2026-10-30 Add V4 concept sketch (sketch only, no CAD): servo on top, thicker parts, electronics bay, screwed transition
    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
2026-10-31 Add V4: servo on top, thicker limiter and rotor parts, electronics bay, screwed transition (Option B)
    Module mode 4. Housing 94.3 mm, 103.4 mm from housing bottom to servo top, printed set 143 g
    (113 g core + sled + transition ring). Mercury V1 altimeter, 2S LiPo and 5 V regulator bay. Limiter moved
    to the bottom (finger 6 mm, stops 7.6 mm), crown arms 8 x 5 mm, cam web 5.5 mm. Studios, ASM-V4, STEP/STL,
    figures, guide, history. V1, V2, V3 verified unchanged.
    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
2026-10-31 Add V4 power and wiring document: battery and regulator recommendation, wiring schematic
    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
2026-10-31 V4: resize electronics sled battery pocket for the Spektrum 300 mAh 2S (42 x 19 x 12 mm)
    Pocket 42.8 x 19.8 x 12.4 mm, lower sled block 46.8 x 23.8 mm clipped to R25.5, housing height unchanged.
    Rebuilt V4 studios and assembly, no printed-part overlaps, refreshed sled STL, STEP, figures and documents.
    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
2026-11-01 V4: add battery strap channels to the sled and strap notches to the transition ring
    Two channels at x = +-17.0..21.4 (1 mm top groove, ribs notched) and two 6.3 x 29 x 1.8 mm notches in the
    transition ring. A swept 3.4 mm band touches nothing; no printed-part overlaps. Rebuilt studios, assembly, STLs, STEP, figures, documents.
    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
2026-11-01 V4: apply design-review change list and add wiring layout plan
    Wider flared bearing spokes, limiter stop 1 shortened (no seam wedge), enclosed voids filled, catch-cap finger root fillet,
    ledge pilots O1.8, transition screws M3x10, export orientation rule (rotor hub down, fin on flat side).
    Rebuilt studios and assembly, no printed-part overlaps, rotor sweep unchanged, refreshed STLs, STEP, figures, guide.
    New docs/V4_wiring_layout_plan.pdf: harness routes drawn on the model, four wiring conflicts found, changes proposed (not applied).
    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
2026-11-02 V4: cut the wire paths into the model from the Mercury pin photo
    Bay 2.0 mm longer for wire headroom (housing 96.3 mm), servo-cable groove on the 135 deg strip with a hole into the bay,
    wire trough along the sled centre wall, battery-lead notch, three vent holes, Mercury header orientation (GND, GP6, GP7, OUT, IN, 3V).
    V1-V3 volumes identical, no printed-part overlaps, rotor sweep unchanged. Rebuilt studios and assembly, STLs, STEP, figures, guide and wiring layout document.
    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
2026-11-02 Add modular airbrake concept drawing document (swappable module, reusable electronics head)
    Concept only, nothing built in CAD: head with servo, Mercury, regulator and battery on top, consumable module, base ring;
    interfaces I1-I3, swap procedure, interface details, head layout, change list against V4, breakage strategy, risks.
    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
2026-11-03 Add V5 insert concept: one BT80 tube cut once, swappable module and head inserts, window options, swap procedure, 1:1 tube template
    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
2026-11-03 Add V5 final plan (corrected stack with the BT80 to BT70 transition, tape answer, decisions, CAD build plan); update the tube template for the 12 mm transition spigot
    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
2026-11-03 V5: add the transition quick sketch; correct the tube window size (67 x 63.5 mm measured on the V4 reference tube, not 43 mm) in the insert concept, final plan and tube template
    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
2026-11-03 V5 sketch 3: the sleeve in the bolt path, the no-sleeve option, and a one-piece housing (no seam, no snap hooks, no band)
    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
2026-11-03 Build V5: modular airbrake as mode 5 (one-piece module, head, transition, tube), checked in CAD
    FeatureScript mode 5 on top of V4 (tools/build_fs_v5.py, exec'd by build_fs.py; V1 to V4 volume-identical in all 8 states):
    - module: one-piece housing (no seam), limiter finger and stops above the bearing ring, integral catch caps, M3 hinge bolt + nut,
    hex nut pockets for the 4 module bolts, hinge access channels, housing kept inside R32.2
    - head: cup + lid, servo ledge posts, electronics pockets, vents, USB-C window, switch slot; set-1 bolts clamp cup and lid
    - transition (BT80 side only, placeholder cone), one-piece reference tube with 4 windows and 12 clearance holes
    - 12 radial M3x8 bolts +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
2026-11-04 V5 post-print fixes (work in progress): stiffer fin root, under-hinge tail lock, head seating; FEA tool
    From the friend's printed V5 (photos): fins too flimsy / nearly snap past 90 deg, servo part stands proud of the housing.
    Fin (build_fs_v5.py, mono only, V1 to V4 unchanged):
    - FEA (tools/fea_fin.py, voxel hex mesh, scikit-fem) put the peak stress at the end of the narrow root gusset (16 to 20 MPa at 15 N tip / 30 N airflow)
    - wide tapered gusset, thicker root pad, arc-shaped landing and stop block, spine and edge ribs, root clipped to R32.21
    - mentor-inspired lock: tail under the hinge, U pocket in the stop blocks, keeper towers and pads (meets at about 91 deg); limiter stop 2 trimmed
    He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
2026-11-04 V5 post-print fixes: final build, exports, guide section 9, handoff 0.8
    Stiffer fin root and ribs, under-hinge tail lock with keeper, servo gear boss and deeper hub socket, head sleeve loosened.
    FEA (tools/fea_fin.py): peak stress 8.0/20.1/15.8 -> 4.0/9.9/9.6 MPa; pin load with keeper 10/25/22 -> 1/3/1 N. Not physically tested.
    V5-A/V5-B rebuilt in place, ASM-V5 recreated (new id). exports/v5 regenerated. V1 to V4 volumes identical in 8 states.
    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
2026-11-04 P1S: split into two plates with an almost even filament split (replaces the one-plate layout)
    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
2026-11-04 V5: servo mount raised 3.2 mm for screw clearance, screw clearance audit, fin area script, new exports and plates
    - head stack above the servo ledges raised by hz=3.2 mm so servo screws up to M2x10 clear the rotor hub (second tab hole is over the hub); M2x8 modelled
    - servo-screw access holes cut through the pocket rims
    - tools/check_screws.py (longest bolt that clears, per fastener set), tools/fin_area.py
    - V5-A/B rebuilt, ASM-V5 repaired in place (same id), V1..V4 identical in 8 states
    - STL/STEP and both P1S plates regenerated; guide section 10, handoff 0.10
    Claude-Session: https://claude.ai/code/session_017cUi45VFHosaRMxpUtqwm8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
2026-11-04 V5: redesign the servo mount so the servo can actually be assembled (ledges above the tabs, bolts from below)
    The earlier CAD had the servo tabs on top of the ledges, which cannot be assembled (from below the tab hits the ledge, from above the floor blocks);
    the printed part therefore had the servo hung under the ledges and the screw heads hit the rotor hub rim (user screenshot).
    - ledges moved above the tabs, M2 nut recesses on the underside, no floor screwdriver holes, servo pushed up from below, M2x8 bolts from below, heads 3.5 mm above the hub
    - hz shift reverted to 0 (replaces the 3.2 mm raise); rotor unchanged: only the head cup is reprinted
    - new checks (servo insertion path, driver c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
2026-11-04 Servo sketch: reverse direction, move at full servo speed
    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
2026-11-05 V5 head cup: widen the two servo arms into the sleeve wall (arm broke at the cup)
    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
